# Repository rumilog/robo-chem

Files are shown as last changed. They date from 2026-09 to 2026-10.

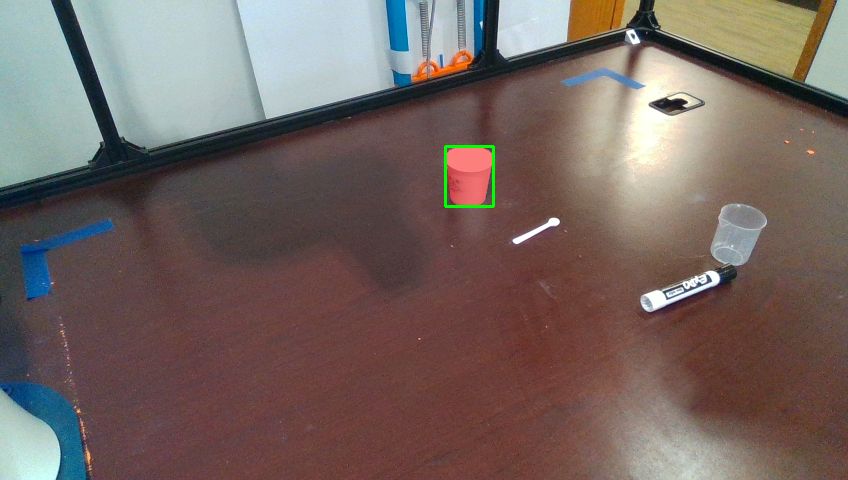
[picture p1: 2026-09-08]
diag_out/mask_white_paper_cup_cam2.png

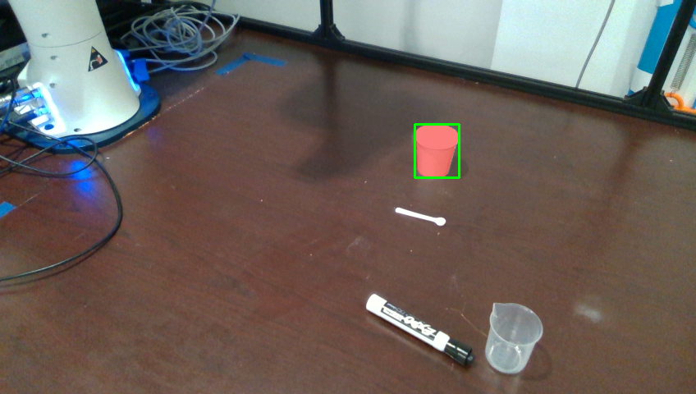
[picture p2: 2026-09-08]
diag_out/mask_white_paper_cup_cam3.png

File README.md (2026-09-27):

# robo-chem

Autonomous robotic chemist stack for a **Franka Panda** arm in a **RealSense** camera cage. Skills use multi-view SAM 3 segmentation, fused 3D localization, and frankapy motion. A VLM orchestrator can plan tasks; individual skills can also be run directly from the CLI.

Barati Farimani Lab, CMU.

---

Working in this repo: read [`progress.md`](progress.md) before you start and
update it when you finish — see [`CLAUDE.md`](CLAUDE.md).

## Requirements

| Piece | Notes |
| --- | --- |
| Franka + `franka-interface` / ROS Noetic | Control PC stack under `/home/rumi/frankapy` |
| Python 3.8 venv with frankapy | `/home/rumi/franka` (activated by `scripts/env.sh`) |
| Perception env (Python 3.10) | `perception_env/` — runs the grounding service |
| SAM 3 weights | `weights/sam3.pt` (see `scripts/fetch_sam3.py`) |
| OpenAI API key (optional) | `.env` / `OPENAI_API_KEY` for VLM planning and labelled-cup matching |

Do **not** stream all four RealSense cameras at once — capture is sequential (open → frame → close) to avoid USB bus freezes.

---

## Quick start

### 1. Robot / ROS env

```bash
cd /home/rumi/Desktop/robo-chem
source scripts/env.sh
```

### 2. Grounding service (separate terminal)

```bash
cd /home/rumi/Desktop/robo-chem
perception_env/bin/python perception_service/grounding_service.py \
  --backend sam3 --model weights/sam3.pt --no-exemplars
```

Service listens on `http://127.0.0.1:5005` by default. The printed scoop is
the text prompt `"white plastic tool"`. Exemplar matching (DINOv2 plus a
second SAM, for the stirrer and the holder) stays unloaded unless you pass
`--exemplars exemplars`. See `exemplars/README.md`.

### 3. Run a skill

```bash
source scripts/env.sh
python scripts/run_experiment.py --skill pick_up \
  --params '{"object_name":"plastic beaker","z_offset":0.02,"squeeze":0.013}'
```

---

## Validated skill commands

### Pick beaker (upright top-down)

```bash
python scripts/run_experiment.py --skill pick_up \
  --params '{"object_name":"plastic beaker","z_offset":0.02,"squeeze":0.013}'
```

Opens the gripper, **`reset_joints`** (joint-space home) before scanning, then top-down grasp. Closing uses measured width − squeeze.

### Pick spoon (lower workspace floor)

```bash
python scripts/run_experiment.py --skill pick_up \
  --workspace-min 0.25 -0.40 -0.13 \
  --params '{"object_name":"larger spoon","z_offset":0.0,"grasp_force":1.0}'
```

### Pour into white paper cup

```bash
python scripts/run_experiment.py --skill pour \
  --params '{"target_container":"white paper cup","pour_angle":90,"hold_duration":2,"forward_offset":-0.08}'
```

- `reset_joints` before scanning and again after the pour hold
- Tips toward the robot base (−X) to 90°
- Each 10° tip step advances the EE **+X by 0.25 cm** (`tip_advance_m`) so the mouth stays over the cup
- Tune `forward_offset` / `tip_advance_m` if the stream misses the cup

### Scoop from a labelled cup

Cups sit on handwritten labels (`CITRIC ACID`, `BAKING SODA`, …). Locate matches label → cup via GPT-4o + multi-instance SAM:

```bash
python scripts/run_experiment.py --skill scoop \
  --workspace-min 0.25 -0.40 -0.13 \
  --params '{"powder_source":"citric acid","tool_length":0.08}'
```

Offline label check (no robot):

```bash
python scripts/check_labeled_cups.py \
  --images-dir "scene_captures/spoon graspped_20260909_155259" \
  --label "citric acid" \
  --out-dir diag_out/labeled_cups
```

---

## Repository layout

```
robo-chem/
├── robochem/                 # Python package
│   ├── skills/               # pick_up, pour, scoop, place, …
│   ├── agents/               # LLM planner: scene → plan → skill call
│   ├── vision/               # multi-cam localizer, grasp analyzer, grounding client
│   ├── orchestrator/         # the closed loop over the agents and the skills
│   └── verification/         # chemistry outcome checks
├── perception_service/       # Flask SAM 3 / GroundingDINO / exemplar service
├── scripts/
│   ├── env.sh                # ROS + frankapy + PYTHONPATH
│   ├── run_experiment.py     # main skill / task entry
│   ├── calibrate_cameras.py  # board-free cube calibration
│   ├── capture_scene.py      # dump color/depth stills
│   ├── register_object.py    # teach an object SAM cannot be told about
│   └── smoke_test_*.py
├── weights/                  # sam3.pt, etc.
├── exemplars/                # objects registered by appearance, not by name
├── calibration_out/          # extrinsics, taught poses
├── diag_out/                 # debug overlays / fused clouds
├── scene_captures/           # saved multi-cam scenes
├── progress.md               # detailed status & known-good params
└── IMPLEMENTATION_PLAN.md    # longer design notes
```

---

## Skills

| Skill | Role |
| --- | --- |
| `pick_up` | Segment → fuse → top (or side) grasp → lift |
| `pour` | Locate target → tip toward base → hold → `reset_joints` |
| `scoop` | Dig from a powder source (optionally by reagent label) |
| `place`, `dispense`, `stir`, `move_to`, `tilt` | Other manipulation |
| `open_gripper` / `close_gripper` | Gripper |
| `analyze_scene`, `locate_object`, `check_container` | Perception |

Many skills besides `pick_up` / `pour` are less hardened (workspace clamps, reach retries, pre-scan home).

Run any skill:

```bash
python scripts/run_experiment.py --skill <name> --params '<json>'
```

---

## Natural-language tasks (the LLM agents)

`--task` runs the agent pipeline in [`robochem/agents/`](robochem/agents/): it
looks at the bench through the cage, plans sub-tasks, chooses a skill and its
parameters for each one, executes them, and replans when one fails. It is
robomail_Aliyah's multi-agent planner — structured output, a robot capability
profile, closed-loop correction — with its fake executor replaced by the real
`SkillsExecutor`.

```bash
source scripts/env.sh
python scripts/run_experiment.py --task "Scoop citric acid into the white paper cup"
```

**See the plan without moving the arm.** `--dry-run` runs every LLM stage and
prints the skill call it would make for each sub-task, then stops. This is the
cheap way to check a task before committing the bench to it:

```bash
perception_env/bin/python scripts/run_experiment.py --sim --no-viewer --dry-run \
    --workspace-min 0.25 -0.40 -0.13 \
    --task "Scoop citric acid into the white paper cup"
```

```
[scene] 4 objects: citric acid cup, larger spoon, plastic beaker, white paper cup
[plan] 4 sub-tasks
   1. Pick up the larger spoon
   2. Scoop citric acid from the citric acid cup with the held larger spoon
   3. Dump the loaded larger spoon into the white paper cup
   4. Place the larger spoon beside the citric acid cup
```

Drop `--dry-run` and the same run executes. Step 2 then comes out as:

```
[step 2] Scoop citric acid from the citric acid cup with the held larger spoon
   -> --skill scoop --params '{"powder_source": "citric acid cup",
                               "tool_offset": [-0.0306, -0.0015, 0.0039]}'
```

That `tool_offset` is not a number the model invented, and it is not in the dry
run either: `pick_up` measured it off the point cloud at the moment it grasped
the spoon, and the orchestrator put it in the prompt for the next step. A dry run
grasps nothing, so there is nothing to measure and the parameter is absent.

| Flag | Effect |
| --- | --- |
| `--dry-run` | Plan in full, execute nothing |
| `--max-retries N` | Corrective replanning attempts (default 3) |
| `--no-verify` / `--verify` | Chemistry check at the end. On by default on hardware, off in `--sim`, which has no chemistry to check |
| `--legacy-planner` | The older single-prompt `VLMOrchestrator` |

Every run writes a JSON record to `--log-dir` (default `experiments/`) holding the
scene, every plan and correction, every skill call with its parameters, and what
each one returned.

### How the pieces fit

| Stage | Module | Does |
| --- | --- | --- |
| Scene | `agents/scene.py` | Names what is on the bench, using names perception can actually resolve |
| Plan | `agents/planner.py` | Goal → ordered sub-tasks; also the corrective replan |
| Skill call | `agents/skill_planner.py` | One sub-task → one `SkillsExecutor` call, with parameters |
| Vocabulary | `agents/skill_catalog.py` | The closed skill list, generated from `SKILL_REGISTRY` |
| Loop | `orchestrator/agent_orchestrator.py` | Executes, tracks the gripper, replans on failure |

Three things are deliberate and worth knowing:

- **The model does not author trajectories.** It picks the skill and its
  arguments; the motion inside each skill is hand-written and grounded by SAM 3.
  This is a weaker autonomy claim than robomail_Aliyah's "all motion comes from
  the LLM Step Planner", and every trial record says so under `provenance`.
- **Object names are grounded, not captions.** A name goes straight to
  `VisionSystem.locate`. Where the cell can enumerate its bench — the simulator
  can — the scene agent must name objects from that inventory, so it cannot plan
  against a "measuring scoop" the bench calls a "larger spoon".
- **Tool offsets come from perception.** `pick_up` measures where a grasped
  tool's working end sits and reports it; the orchestrator hands that
  measurement to the agent planning the next step rather than letting the model
  guess a number it cannot see.

Instead of a typed task, `--instruction-image` reads the goal off a photographed
protocol page.

**Status.** Exercised end to end in `--sim`: plan, execute, an autonomous replan
after a failed `place`, success. With granules on, 2 of 90 citric acid grains
reached the paper cup — the scoop's yield is limited by `measure_tool_offset`
reading the bowl 24 mm shallower than CAD, which is a perception limitation that
predates this pipeline (see `progress.md`). **Not yet run on the arm.** The hardware path
differs in two ways worth watching the first time: object names are open
vocabulary rather than a bench inventory, so a name the scene agent invents can
fail to ground; and verification is on by default.

---

## Calibration & perception

1. Prefer **live RealSense factory intrinsics** (old `.intr` files were corrupt).
2. Extrinsics: green cube in gripper + Kabsch (`scripts/calibrate_cameras.py`).
3. Validate with `scripts/validate_calibration.py` / `scripts/check_object.py`.
4. Prefer prompt **`plastic beaker`** for the red translucent beaker; use **`--backend sam3`**.
5. The printed scoop is the prompt **`white plastic tool`**. Appearance
   matching for the stirrer and holder is opt-in (`--exemplars exemplars`);
   it is off by default because DINOv2 plus a second SAM exhausts RAM
   (`exemplars/README.md`).

---

## Simulation (no robot, no cage)

`robochem/sim/` runs the **same skills** against a MuJoCo Franka Panda so motions
can be watched before they touch hardware. The arm is mujoco_menagerie's vendor
Panda model with the Franka Hand; the four cage cameras are placed at the
extrinsics in `calibration_out/` and given the cage's frame geometry (848x480 at
a 42.5° vertical field, so fx = fy ≈ 617 as the D435 reports), rendered for
depth and segmentation, and back-projected through the project's own
`ObjectLocalizer` / `VisionSystem` fusion — so perception really reconstructs
the props from four views, with real self-occlusion, and rejects them when the
views disagree.

`SimFrankaArm` implements the frankapy surface the skills use and `SimVision`
the `VisionSystem` surface, so `SkillsExecutor` is unmodified. The simulator has
**no frankapy and no ROS**, so it runs out of `perception_env` (Python 3.10),
*not* the robot venv — do **not** `source scripts/env.sh` first.

### Setup (once)

```bash
bash scripts/setup_sim.sh
```

Reuses `perception_env/` if present, otherwise builds `sim_env/`; installs the
dependencies, pre-fetches the Panda MJCF into `~/.cache/robot_descriptions/`,
and runs the smoke test. Full setup notes, including a fresh machine after a
`git pull`, are in [`robochem/sim/README.md`](robochem/sim/README.md).

### Run a skill in the viewer

```bash
perception_env/bin/python scripts/run_experiment.py --sim \
  --skill pick_up --params '{"object_name":"plastic beaker","z_offset":0.02,"squeeze":0.013}'

perception_env/bin/python scripts/run_experiment.py --sim --sim-granules \
  --skill pour --params '{"target_container":"white paper cup","pour_angle":90,"hold_duration":2,"forward_offset":-0.08}'

perception_env/bin/python scripts/run_experiment.py --sim \
  --workspace-min 0.25 -0.40 -0.13 \
  --skill scoop --params '{"powder_source":"citric acid","tool_length":0.08}'
```

| Flag | Effect |
| --- | --- |
| `--sim-speed N` | Genuinely moves the arm N× faster (compresses commanded durations). Fling-and-spill at high N is real, not an artifact — use `1.0` when granule behaviour matters. |
| `--sim-fast` | Keeps commanded durations, just skips the wall-clock wait. This is the flag for "same motion, less waiting". |
| `--no-viewer` | Headless (CI, remote shells) |
| `--sim-granules` | Loose particles in the beaker and reagent cups, so pours and scoops move material |
| `--sim-tool-length M` | Bolt a fixed tool of length M onto the hand and move `franka_tool` out to its tip |
| `--sim-grasp-mode` | `magnet` (kinematic attach on close, default) or `physics` (friction contacts) |
| `--sim-hold S` | Seconds to keep the window open afterwards (default: until you close it) |

### From Python

```python
from robochem.sim import build_cell

cell = build_cell(viewer=True, granules=True)
cell.skills.execute("pick_up", {"object_name": "plastic beaker", "z_offset": 0.02})
cell.arm.hold()      # keep watching
cell.close()
```

Edit the bench (what is on the table, and where) in `robochem/sim/bench.py`.

### What it is and is not

- Cartesian targets are solved by damped least-squares IK over the seven arm
  joints and tracked to **under a millimetre**, with gravity compensated as the
  real controller does. An unreachable target leaves the arm short, so the
  skills' own arrival checks fire rather than being papered over.
- Reconstructed centroids land within a few millimetres of truth for the cups;
  the spoon reads ~25 mm off its body origin because its point cloud includes
  the bowl.
- It does **not** model fluid, powder rheology, RealSense noise characteristics,
  frankapy impedance, or force thresholds. Granules are bouncy spheres — they
  show *where a stream goes*, not how a powder behaves.

---

## Smoke tests

```bash
# Gripper / small moves only (no vision)
python scripts/smoke_test_motion.py
python scripts/smoke_test_motion.py --move

# Pick (+ optional pour) with pauses
python scripts/smoke_test_skills.py
python scripts/smoke_test_skills.py --pour
```

No hardware needed (run these from `perception_env`, without `scripts/env.sh`):

```bash
# Skill geometry and failure logic against a fake arm
perception_env/bin/python scripts/test_skills_offline.py

# The agent loop against a fake model: vocabulary, parameter checking,
# gripper bookkeeping, replanning. Needs no API key.
perception_env/bin/python scripts/test_agents_offline.py

# Perception + motion + pick/pour/scoop against the simulated cell
perception_env/bin/python scripts/smoke_test_sim.py
perception_env/bin/python scripts/smoke_test_sim.py --viewer --speed 2
```

---

## Related docs

| Doc | Contents |
| --- | --- |
| [`progress.md`](progress.md) | Current validated commands, design choices, known issues |
| [`IMPLEMENTATION_PLAN.md`](IMPLEMENTATION_PLAN.md) | Broader architecture plan |
| [`SKILLS_ROADMAP.md`](SKILLS_ROADMAP.md) | Skill hardening roadmap |
| [`robochem/sim/README.md`](robochem/sim/README.md) | MuJoCo preview of the cell: setup, usage, troubleshooting |
| [`robomail/docs/progress.md`](robomail/docs/progress.md) | Older PLATO / agent-pipeline notes |

---

## License / attribution

Research software for the Autonomous Robotic Chemist project (Barati Farimani Lab). Robot control depends on frankapy / Franka; perception on Meta SAM 3 and RealSense; simulation on MuJoCo and the Franka Panda model from DeepMind's mujoco_menagerie (Apache-2.0).

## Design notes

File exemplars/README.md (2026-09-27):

# Registered objects (exemplar vocabulary)

One `.npz` per custom object: DINOv2 embeddings of reference crops you boxed by
hand. These are the vocabulary for things SAM 3 has no word for — the printed
stirrer, the cranked scoop — and they are cell calibration, same as
`calibration_out/`: small, and meant to be committed.

## Why these exist

SAM 3 is open-vocabulary, not unlimited. `scripts/sweep_prompts.py` spent twenty
phrases on the printed scoop and the best honest hit was `"scoop"` on 2/4
cameras; the stirrer sweep in `diag_out/stirrer_prompts/` is the same story. The
phrases that score *well* (`"white object"`, 0.95 on 4/4) are matching the cups.
No wording fixes this — the concept is not in the model.

So these objects are matched by appearance instead. The grounding service
segments everything in the frame with SAM's automatic mask generator (no prompt,
class-agnostic), embeds each candidate, and returns whichever one looks most like
a reference here. See `perception_service/exemplar_matcher.py`.

## Adding an object

```bash
# 1. put it on the bench, photograph it from every camera
source scripts/env.sh
python scripts/capture_scene.py --label stirrer

# 2. drag a box around it once per camera
perception_env/bin/python scripts/register_object.py --name stirrer \
    --images-dir scene_captures/stirrer_<ts>

# 3. start the grounding service WITH the library (off by default; DINOv2
#    plus a second SAM is too much RAM on this host):
#    perception_env/bin/python perception_service/grounding_service.py \
#        --backend sam3 --model weights/sam3.pt --exemplars exemplars
# 4. check it, and LOOK at the overlays
python scripts/sweep_prompts.py --images-dir scene_captures/stirrer_<ts> \
    --only stirrer --save-overlays diag_out/stirrer_exemplar
```

Register from several captures (`--images-dir` is repeatable) when the tool will
be seen in genuinely different poses — lying on the bench and standing in its
holder are not the same view.

## Two things that silently cost you a match

**Aliases.** `GroundingClient._resolve` rewrites names through
`SAM_PROMPT_ALIASES` *before* the service sees them, and dispatch here is by
name. A skill asking for `"rectangular scoop"` sends `"white plastic tool"`, so
the scoop must be registered with that phrase as an alias or it is never
consulted:

```bash
perception_env/bin/python scripts/register_object.py --name scoop \
    --images-dir scene_captures/new_scoop_<ts> --alias "white plastic tool"
```

`register_object.py` warns when it spots this.

**The model id.** Every file records the encoder that made it. Embeddings from a
different encoder are not comparable to anything the service computes, so a
mismatched file is skipped with a warning rather than scored — re-register if
`EMBED_MODEL_ID` in `exemplar_matcher.py` ever changes.

## Register what you want to GRASP

`ObjectLocalizer.get_object_pose` puts the grasp at the **mean of the fused mask
points**, so the mask defines where the gripper goes. Register the part you mean,
not the assembly it is sitting in.

The stirrer is the white cube; the black cylinder under it is its holder. A first
pass registered "stirrer" as cube + cylinder together, which scored beautifully
(0.95+) and would have driven the gripper into the middle of the *holder*. They
are now two objects — `stirrer` and `stirrer holder` — which also gives
place-back something to aim at, and keeps `stirrer` recognisable once it has been
lifted out and the assembly no longer exists.

A high score means "this is the shape you showed me". It says nothing about
whether that shape was the right thing to show.

## Register every state the object will be seen in

A holder with the tool in it and a holder standing empty are different pictures.
`stirrer_holder.npz` carries both — four views with the stirrer seated (its top
occluded) and four of the empty bore — because the holder gets looked for in
both states: occupied before a pick, empty when deciding where to put the
stirrer back. They are only 0.49-0.83 similar to each other, so one does not
stand in for the other.

The same applies to a tool that will be seen lying on the bench *and* standing
in its holder. `--append` adds views to an existing object; it never replaces
them.

## Multi-part objects

Box the WHOLE tool when you register, even if it is two colours. A two-tone
object is several objects to the mask generator — the stirrer's black body, the
white cube's top and the cube's shaded front face come back as three separate
masks — so no single candidate is ever the whole thing. The matcher glues
neighbouring pieces back together for as long as that improves the match against
your reference, which took the stirrer from 0.64 (body only, head cut off) to
0.95 on cam2. You do not have to do anything for this; it just means the
reference should be the shape you actually want back.

## When something is not found

The point grid is what finds candidates at all, and at the default 32x32 over an
848x480 frame the points land ~26px apart — wider than the scoop's shank. That
produced half a scoop on one camera, and half a scoop legitimately resembles the
stirrer cube more than it resembles a scoop, so the match was refused. The
service retries a missed frame at 48x48 (`--exemplar-retry-points`), which costs
~9s instead of ~4s but only on frames that actually missed.

A per-camera miss is not a failure of the run: localization fuses whatever
cameras did find the object, and three good views beat four with a bad one.

## Reading the numbers

`register_object.py` prints how well the object stands apart: how much its own
views agree, and its best similarity to every other registered object. Own views
at 0.9 and the nearest neighbour at 0.5 is a clean object. Own views at 0.5 and a
neighbour at 0.8 means the crops are mostly table, and no threshold will save it —
register tighter boxes, or make the objects visually different (colour is the
cheap fix). The suggested `--exemplar-thresh` sits between the two.

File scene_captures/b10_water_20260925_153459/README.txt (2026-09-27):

Workstation scene stills for offline perception benchmarking.
Captured: 20260925_153459
Label: b10_water
Cameras: RealSense static cage cams (848x480 BGR + Z16 depth).
Files:
  cam{N}_color.png     - BGR color frame
  cam{N}_depth.png     - raw 16-bit depth (mm)
  cam{N}_depth_viz.png - colorized depth for quick viewing

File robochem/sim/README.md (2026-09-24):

# Simulated Franka cell (`robochem.sim`)

A MuJoCo model of this lab's cell — Franka Emika Panda, Franka Hand, four-camera
RealSense cage — that the **real skills run against unmodified**, so arm motions
can be watched and debugged with no hardware present.

> **Setting this up on a new machine?** Run `bash scripts/setup_sim.sh` from the
> repo root and skip to [Verify](#3-verify). The rest of this file explains what
> that does and how to use the result.

---

## What it actually simulates

`SkillsExecutor` talks to the arm through thirteen methods and to perception
through the `VisionSystem` surface. `SimFrankaArm` and `SimVision` implement
those two surfaces, so **no skill code is aware of the simulator**:

- **Arm** — mujoco_menagerie's vendor Panda MJCF (real link geometry, joint
  limits, Franka Hand). Cartesian targets are solved by damped least-squares IK
  over the seven arm joints and tracked to under a millimetre, with gravity
  compensated the way the real controller does. An unreachable target leaves the
  arm short, so the skills' own arrival checks fire instead of being papered over.
- **Perception** — each of the four cage cameras is placed at the measured
  extrinsics from `calibration_out/` and rendered for depth and segmentation in
  the real frame geometry: 848x480 at a 42.5° vertical field, which is the D435
  colour stream the cage runs and the intrinsics its depth is deprojected with
  (fx = fy ≈ 617, cx = 424, cy = 240). A prop at the edge of a real view is at
  the edge of the simulated one.
  The segmentation supplies the mask SAM 3 would have produced; everything after
  that is this project's own code — `ObjectLocalizer._depth_to_points`,
  `_transform_points`, `VisionSystem._filter_by_consensus`, `_check_plausible`.
  So a skill sees a genuine multi-view point cloud with real self-occlusion, and
  perception fails the same way when a container is hidden from too many cameras.
- **Grasping** — closing the jaws on a prop attaches it kinematically and reports
  the prop's width back through `get_gripper_width()`, which is what a real grasp
  stalling on an object looks like. `grasp_mode="physics"` uses friction instead.

### What it does not simulate

Fluids, powder rheology, RealSense noise characteristics, frankapy impedance
behaviour, or force thresholds. Granules are bouncy spheres: they show *where a
stream goes*, not how a powder behaves. Depth is also complete where the real
sensor drops out — the simulated beaker returns depth through its transparent
wall, so a passing sim run does not prove the real cage can see a clear
container.

---

## Setup

### 0. Prerequisites

| Need | Detail |
| --- | --- |
| Python | 3.9+. Verified on **3.10** and **3.13** |
| Disk | ~500 MB — mujoco_menagerie is cloned to `~/.cache/robot_descriptions/` on first use |
| Graphics | Any OpenGL. A display for the viewer window; `MUJOCO_GL=egl` for headless |
| **Not** needed | frankapy, ROS, RealSense, SAM weights, `OPENAI_API_KEY` |

The camera extrinsics (`calibration_out/realsense_camera{2,3,4,5}w.npy`) **are
committed**, so a fresh clone gets the real cage geometry. If they are ever
missing the scene falls back to a synthetic camera ring and says so:

```
[sim] No calibration in calibration_out; using a synthetic camera ring
```

`calibration_out/` holds the **measured** extrinsics from the last
`scripts/calibrate_cameras.py` sweep. The robot reads a *different* copy —
`robomail/robomail/vision/calib/`, which `calibrate_cameras.py --apply` installs
into. Until that install runs the two disagree (in this checkout by about 4 cm;
see `shift_from_current_mm` in `calibration_out/report.json`), and a simulated
camera is not where the robot believes its camera is. To preview against what
the robot is actually running, point the sim at the same files:

```bash
sim_env/bin/python scripts/run_experiment.py --sim \
  --sim-calib-dir robomail/robomail/vision/calib ...
```

### 1. Environment

Python environments are **not** in git (`perception_env/`, `sim_env/` are
ignored), so a fresh clone has none. Build one:

```bash
cd /path/to/robo-chem
bash scripts/setup_sim.sh
```

That reuses `perception_env/` if it exists, otherwise creates `sim_env/`, then
installs, pre-fetches the model and runs the smoke test. Pass a path to target a
specific env (`bash scripts/setup_sim.sh path/to/venv`), or set `SKIP_TEST=1` to
install without verifying.

> **Do not `source scripts/env.sh` first.** That activates the Python 3.8
> frankapy venv and sources ROS. The simulator needs neither and will not run
> there.

#### On Windows

`setup_sim.sh` assumes a POSIX venv layout (`bin/python`), so do it directly —
the interpreter lives in `Scripts\` and the rest is identical:

```powershell
winget install --id Python.Python.3.12 -e --scope user
& "$env:LOCALAPPDATA\Programs\Python\Python312\python.exe" -m venv sim_env
sim_env\Scripts\python.exe -m pip install numpy mujoco robot_descriptions opencv-python scikit-learn openai Pillow
sim_env\Scripts\python.exe scripts\smoke_test_sim.py
```

The viewer and offscreen rendering both work through WGL; there is no `MUJOCO_GL`
to set, and `egl` is not available. If `import mujoco` dies with `WinError 1114`,
see Troubleshooting — the Visual C++ runtime needs updating.

<details>
<summary>Manual equivalent, if you would rather not use the script</summary>

```bash
python3 -m venv sim_env
sim_env/bin/pip install numpy mujoco robot_descriptions opencv-python scikit-learn openai Pillow
```

`numpy`, `mujoco` and `robot_descriptions` drive the simulation. `opencv-python`,
`scikit-learn` and `openai` are imported on the way into `robochem.vision`, which
`SimVision` subclasses so reconstruction runs through the real fusion code.
`Pillow` comes in through `ExperimentLogger`, which `run_experiment.py` imports
at module level whether or not the run is simulated. `open3d` is **not**
required — nothing on the simulated path uses it.

Check it with `sim_env/bin/python scripts/run_experiment.py --help`, which
exercises every module-level import and should exit 0.
</details>

### 2. First run downloads the model

The first call clones mujoco_menagerie (a few hundred MB) with a progress bar.
`setup_sim.sh` does this up front so a later run does not appear to hang.

### 3. Verify

```bash
sim_env/bin/python scripts/smoke_test_sim.py
```

Expected tail — **all five groups must pass**:

```
====================================================
  PASS  perception
  PASS  motion
  PASS  pick + pour
  PASS  pick + scoop
  PASS  failure handling
====================================================
all groups passed
```

Add `--viewer` to watch it (`--viewer --speed 2`). Takes a few minutes headless.

`--only` runs just the groups whose name contains what you pass, which is how you
watch one sequence end to end — the skills run against **one** cell, so the spoon
is still in the jaws when `scoop` starts:

```bash
sim_env/bin/python scripts/smoke_test_sim.py --viewer --granules \
  --only scoop --speed 2 --hold 0
```

`--hold 0` leaves the window open until you close it instead of the default five
seconds. Running `pick_up` and then `scoop` as two `run_experiment.py --sim`
commands does **not** work: each process builds its own cell, so the second one
starts with an empty gripper and `scoop` refuses.

---

## Running skills

Same entry point and the same `--params` as the hardware route, plus `--sim`:

```bash
sim_env/bin/python scripts/run_experiment.py --sim \
  --skill pick_up --params '{"object_name":"plastic beaker","z_offset":0.02,"squeeze":0.013}'

sim_env/bin/python scripts/run_experiment.py --sim --sim-granules \
  --skill pour --params '{"target_container":"white paper cup","pour_angle":90,"hold_duration":2,"forward_offset":-0.08}'

sim_env/bin/python scripts/run_experiment.py --sim \
  --workspace-min 0.25 -0.40 -0.13 \
  --skill scoop --params '{"powder_source":"citric acid","tool_length":0.08}'
```

`--skill` can be repeated to run a sequence against one cell; `--params` is
matched to it in order, and a skill given no `--params` runs on its defaults.
This is the only way skills that hand a held tool between them (`pick_up` then
`pour` / `scoop` / `stir`) can work, because a second invocation starts a fresh
cell with an empty gripper. The run stops at the first step that fails and exits
non-zero, naming the step.

| Flag | Effect |
| --- | --- |
| `--sim-speed N` | Genuinely moves the arm N× faster by compressing commanded durations. Spilling at high N is real, not an artifact — use `1.0` when granule behaviour matters |
| `--sim-fast` | Keeps commanded durations, only skips the wall-clock wait. **This** is the flag for "same motion, less waiting" |
| `--no-viewer` | Headless, for CI and remote shells |
| `--sim-granules` | Loose particles in the beaker and reagent cups so pours and scoops move material |
| `--sim-tool-length M` | Bolt a fixed tool of length M (metres) to the hand and move `franka_tool` out to its tip |
| `--sim-grasp-mode` | `magnet` (kinematic attach, default) or `physics` (friction contacts) |
| `--sim-calib-dir DIR` | Where to read `realsense_cameraNw.npy` from. Defaults to `calibration_out/`; point it at `robomail/robomail/vision/calib` to place the cage exactly where the robot currently believes it is |
| `--sim-hold S` | Seconds to keep the window open afterwards (default: until you close it) |

### From Python

```python
from robochem.sim import build_cell

cell = build_cell(viewer=True, granules=True)
cell.skills.execute("pick_up", {"object_name": "plastic beaker", "z_offset": 0.02})
cell.arm.hold()     # keep watching until the window is closed
cell.close()        # always: see the segfault note in Troubleshooting
```

`cell.arm` is the frankapy stand-in, `cell.vision` the `VisionSystem` stand-in,
`cell.skills` an ordinary `SkillsExecutor`. `cell.vision.ground_truth(name)`
gives a prop's true position, for checking what perception did.

### Headless (no display)

```bash
MUJOCO_GL=egl sim_env/bin/python scripts/smoke_test_sim.py
```

`egl` is verified working with `DISPLAY` unset. Offscreen rendering for the
cameras works regardless; only the interactive window needs a display, and it
degrades gracefully:

```
[sim] Viewer unavailable (...); running headless
```

---

## Layout

| File | Role |
| --- | --- |
| [`scene.py`](scene.py) | Compiles the MJCF: Panda + Hand, the `franka_tool` TCP site, the four cage cameras, the table, the props. Also builds the arm-only model used for IK |
| [`sim_arm.py`](sim_arm.py) | `SimFrankaArm` — the frankapy surface, DLS IK, Cartesian interpolation, kinematic grasping |
| [`sim_vision.py`](sim_vision.py) | `SimVision` — renders depth + segmentation, deprojects through the project's real fusion path |
| [`bench.py`](bench.py) | **What is on the table, and where.** Edit here to change the scene |
| [`rigid_transform.py`](rigid_transform.py) | `RigidTransform` shim, so the skills build poses without autolab_core (which exists only in the robot venv) |
| [`../../scripts/smoke_test_sim.py`](../../scripts/smoke_test_sim.py) | End-to-end check: perception, motion, pick+pour, pick+scoop, failure handling |
| [`../../scripts/capture_sim_scene.py`](../../scripts/capture_sim_scene.py) | Colour + depth stills from the simulated cage, in the same filenames `capture_scene.py` writes on hardware |
| [`../../scripts/setup_sim.sh`](../../scripts/setup_sim.sh) | One-command setup on a new machine |

### Changing the bench

Props are described semantically in `bench.py` and compiled to MJCF. Their names
are the queries the skills already use (`"plastic beaker"`, `"white paper cup"`,
`"larger spoon"`), and a `label` makes a cup resolve from a reagent name the way
the real labelled-cup path does:

```python
Prop(name="plastic beaker", pos=(0.46, 0.14), radius=0.035, height=0.095,
     rgba=(0.75, 0.85, 0.95, 0.55), fill=30)          # fill = granules inside
```

The table top is `z = 0`, which is also the Panda's base plane, matching the real
cell where object centroids land just above zero.

### The stirrer and its holder

`stirrer v1.stl` and `stirrer holder.stl` are both on the bench at (0.62, 0.14),
on the same axis. The two are authored in **one assembly frame**, so they take
the same orientation and their heights line up directly: the stirrer starts
seated in the holder, its head resting on the holder's top face and its rod
hanging in the bore. That is the point of the holder — the tool is always
presented upright, so the gripper can take it from straight above like anything
else.

| Part | Geometry |
| --- | --- |
| Stirrer | 30 mm grasp head on a 10 mm ⌀ rod, 66 mm of rod, 96 mm overall. Head centre to rod tip is **81 mm** — that is `tool_length`. |
| Holder | 50 mm ⌀ block, 85 mm tall, bored 12 mm with a chamfer over the top 19 mm. Welded to the bench: it is a fixture. |

The holder is a fixture, so it is deliberately **not graspable** — the stirrer's
head sits directly above it, and without that rule a closing gripper takes the
holder instead.

The full cycle, in one session:

```bash
sim_env/bin/python scripts/run_experiment.py --sim \
  --skill pick_up --params '{"object_name":"stirring rod"}' \
  --skill stir    --params '{"target_container":"plastic beaker","tool_axis":"z","tool_length":0.081,"revolutions":3}' \
  --skill place   --params '{"target_location":"stirrer holder","on_top":true,"release_clearance":0.015,"stop_force_n":1.0}'
```

| Parameter | Why |
| --- | --- |
| `tool_axis: "z"` | The default `"x"` is for a spoon gripped across its flat handle, which has to be stood up with a quarter turn. This rod is gripped end-on and is *already* vertical; the `"x"` check reads that correct pose as 90° off and would tip it flat. |
| `tool_length: 0.081` | Head centre (the TCP) to rod tip. `stir` puts the wrist at `rim_z - stir_depth + tool_length`, so without this the tip never reaches the liquid. |
| `on_top: true` | `place` defaults to setting things down *beside* the target. Without this the stirrer is laid on the bench next to the holder, where it falls over. |
| `release_clearance: 0.015` | Half the head. Only a starting guess when `stop_force_n` is set — the probe begins above it and feels its way down. |
| `stop_force_n: 1.0` | Stop the descent and release the instant the tool pushes back this hard. Contact means the head has landed on the holder's rim, so it is seated. |

The return is a blind insertion: the bore is 2.5 mm wider than the rod, and what
makes it work is the chamfer, which catches a rod arriving up to ~14 mm off axis
and walks it down.

### Seating by force

`place` cannot know where to let go from geometry alone. How far the stirrer
hangs below the TCP changes with every grasp — measured at 6–8 mm of variation
run to run — and the scanned holder height carries a few millimetres of its own
error. `stop_force_n` sidesteps both: descend in `probe_step` increments and
release the moment the tool pushes back harder than the threshold.

Measured curve, pressing the stirrer onto its holder:

| Head underside | Upward force |
| --- | --- |
| 0.0857 m (just clear) | 0.00 N |
| **0.0850 m (on the rim)** | **1.84 N** |
| 0.0843 m | 4.33 N |
| 0.0832 m | 7.11 N |
| 0.0809 m | 11.70 N |

So 1 N triggers within a millimetre of flush, which is the intent. Two details
this depends on:

- `SimFrankaArm.get_ee_force_torque()` matches frankapy's: six floats, base
  frame, signed as the force the world exerts *on* the robot. A magnet grasp
  carries the prop kinematically, so nothing it touches reaches the finger
  joints and a wrist sensor would read zero — the sim sums contacts on
  everything moving with the wrist instead, held prop included.
- The seating faces carry a stiffer `solref`/`solimp` than the MuJoCo default,
  which otherwise squashes for millimetres before pushing back and smears the
  contact event into a ramp no threshold can find.

If the probe never reaches the threshold it keeps hold and fails, rather than
opening the gripper at whatever height the scan produced.

The whole cycle is run by the `pick + stir` group of `smoke_test_sim.py`, and the
refuse-to-drop behaviour by the `force guard` group.

## Troubleshooting

| Symptom | Cause and fix |
| --- | --- |
| `ModuleNotFoundError: No module named 'cv2'` (or `sklearn`, `openai`) | Incomplete install — `robochem.vision` needs them on import. Re-run `scripts/setup_sim.sh` |
| `ModuleNotFoundError: No module named 'mujoco'` | Running the wrong interpreter. The sim is not in the frankapy venv; use the env `setup_sim.sh` built |
| `OSError: [WinError 1114] A dynamic link library (DLL) initialization routine failed` on `import mujoco` (Windows) | The machine's Visual C++ 2015-2022 runtime predates the mujoco wheel, and every mujoco version fails the same way. Confirm it in Event Viewer — Application: a `python.exe` crash naming `MSVCP140.dll` with `0xc0000005`. Fix with `winget upgrade --id Microsoft.VCRedist.2015+.x64` (needs admin; 14.44 or newer works). A venv-local copy of the runtime does **not** help: System32 wins once the DLL is loaded |
| `ImportError: ... frankapy` | You sourced `scripts/env.sh`, or are running the hardware path. `--sim` imports frankapy lazily and never on the simulated route |
| `openai.OpenAIError: Missing credentials` | Only from constructing `VisionSystem` directly. `SimVision` handles this; no key is needed for simulation |
| Process exits `139` / **segmentation fault after the run finishes** | The MuJoCo viewer handle must be garbage-collected before interpreter shutdown. `cell.close()` (and `--sim`) already does this — call it, and do not hold your own reference to `cell.arm._viewer` |
| First run seems to hang | It is cloning mujoco_menagerie. Let it finish, or pre-fetch with `setup_sim.sh` |
| `[sim] jaws closed on nothing` | The gripper closed with no prop between the jaws. Usually a grasp pose that missed, which is the simulator reporting a real failure |
| `[SimVision] Cameras could not agree on 'x'` | Views disagree beyond `consensus_tolerance` — normally the arm occluding the prop. Same rejection the real stack makes |
| Granules fling everywhere | `--sim-speed` above ~2 genuinely accelerates the motion. Use `--sim-fast` instead when you want speed without changed dynamics |

---

## Known accuracy

Measured by `scripts/smoke_test_sim.py` on the default bench:

- Cartesian targets reached to **< 0.5 mm** (hardware `reach_tol` is 35 mm).
- Cup centroids reconstruct within **~1–13 mm** of truth from four cameras.
- The spoon reads **~28 mm** off its body origin — its point cloud includes the
  bowl while the origin is mid-handle. Expected, not an error. It reconstructs to
  **78 x 29 x 26 mm** against the STL's 69.5 x 20.5 x 31.5 mm, the spread being
  depth noise plus PCA axes that do not line up with the CAD axes.
- Pouring at `--sim-speed 1` with `--sim-granules` lands 27/30 particles in the
  target cup, with the median **~3 cm past cup centre in +X** — the `tip_advance_m`
  of 0.25 cm per 10° accumulating. Worth checking against hardware.

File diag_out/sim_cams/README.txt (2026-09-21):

Simulated cage stills, rendered by robochem.sim.
Captured: 2026-09-21T01:01:44
Label: sim
Extrinsics: calibration_out
Cameras: MuJoCo cameras at the cage's measured extrinsics, 848x480, fovy 42.5 (fx = fy = 617, cx = 424, cy = 240).
Files:
  cam{N}_color.png     - BGR colour frame
  cam{N}_depth.png     - 16-bit depth (mm), no sensor dropout
  cam{N}_depth_viz.png - colorized depth for quick viewing
  grid.png             - all cameras on one sheet

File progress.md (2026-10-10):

# Progress — robo-chem (Franka + RealSense)

Last updated: 2026-10-08

Live manipulation stack for the Franka Panda + RealSense cage. Related but
separate from the PLATO/agent notes in [`robomail/docs/progress.md`](robomail/docs/progress.md).

---

## Working commands (validated 2026-09-08 / 2026-09-09)

Prereqs: franka-interface/ROS up, grounding service on SAM 3, then:

```bash
cd /home/rumi/Desktop/robo-chem
source scripts/env.sh
```

Grounding — **one terminal is enough**, background it:

```bash
scripts/grounding.sh start      # idempotent; restart | status | stop | log
```

It has to be its own *process* (perception_env is Python 3.10 for SAM 3; the
skills run in the frankapy Python 3.8 venv) but not its own *terminal*.

Still available by hand if preferred:

```bash
perception_env/bin/python perception_service/grounding_service.py \
  --backend sam3 --model weights/sam3.pt --no-exemplars
```

**DINOv2 is not loaded.** `scripts/grounding.sh` passes `--no-exemplars`.
The printed scoop is the SAM 3 phrase `"white plastic tool"` again
(`scoop`, `rectangular scoop`, `printed scoop`, and `measuring scoop` all
rewrite to it). Exemplar matching still exists and still works — measured
0.95-1.00 on 2026-09-25 — but it loads DINOv2 plus a second SAM on top of
SAM 3, and that combination exhausted this 15GB host. Turn it back on only
with an explicit `--exemplars exemplars` on the python command, not via
`grounding.sh`.

### Pick beaker (upright top-down grasp)

```bash
python scripts/run_experiment.py --skill pick_up \
  --params '{"object_name":"plastic beaker","z_offset":0.02,"squeeze":0.013}'
```

- Opens gripper, **`reset_joints`** (joint-space home) before multi-cam scan
- Upright **top** grasp (no 25° pour tip / spout align)
- Width close = measured diameter − squeeze (`grasp=False`)
  — soft cups still need `"force_limited": false`; default is now close-on-contact

### Pick larger spoon (flat object — lower workspace floor)

```bash
python scripts/run_experiment.py --skill pick_up \
  --workspace-min 0.25 -0.40 -0.13 \
  --params '{"object_name":"larger spoon","z_offset":0.0,"grasp_force":1.0}'
```

- Spoon sits ~z −0.01; default workspace floor (0.015 m) clamps the grasp too high
- `--workspace-min … -0.13` lowers the Z floor so fingers can reach the table
- Force-limited close at 1 N (`force_limited` default True); omit large positive `z_offset`

### Scoop from a labelled cup (reagent name → cup instance)

White paper cups sit on handwritten paper squares (`BAKING SODA`, `CITRIC ACID`,
`RED CABBAGE POWDER`, `Water`). SAM alone cannot tell them apart; locate now:

1. Segments **all** `white paper cup` instances (`return_all` on the grounding service)
2. Asks GPT-4o which label is under each numbered cup
3. Fuses the matching cup in 3D for scoop / pour / place

**Restart the grounding service** after pulling this change (needs `return_all`).

Offline check on stills (no robot):

```bash
python scripts/check_labeled_cups.py \
  --images-dir "scene_captures/spoon graspped_20260909_155259" \
  --label "citric acid" \
  --out-dir diag_out/labeled_cups
```

Scoop (hold the spoon first), using the reagent label as `powder_source`:

```bash
python scripts/run_experiment.py --skill scoop \
  --workspace-min 0.25 -0.40 -0.13 \
  --params '{"powder_source":"citric acid","tool_length":0.08}'
```

- Measure / tune `tool_length` for the held spoon before trusting dig depth
- Direct SAM category names (`plastic beaker`, `larger spoon`, `white paper cup`)
  still skip the label path
- **Camera 2's crop was the cup, not the paper** (2026-09-25,
  `scene_captures/b10_water_20260925_153459`). SAM boxed the clear cup at
  (390, 233)–(457, 302). The 0.9× pad ended at y=331. `B 10 ML WATER` is on
  the sheet in front of the cup, down to about y=450, so the reader saw a
  sliver of `10 ML` and returned null (`labels [none]`). A second mask of
  the same cup (score 0.32) was then greyed over that sliver. The crop now
  follows the white sheet downward and sideways, and does not pad upward
  into the reagent behind the cup — that upward pad made the reader say
  `A 10 ML WATER` and `B 5 ML NaCl` for a crop that also contained the B
  sheet. Re-read of those stills: cam 2 matches `B 10 ML WATER` at score
  0.79, cam 3 at 0.91, cam 5 at 0.89. Cam 4 still reads the B cup as
  `A 10 ML WATER` and is not used.
- **One camera that reads the label is enough** (2026-09-25 dump of
  `B 10 ml water`). Cam 3 read `B 10 ML WATER` at score 0.90, anchor
  `[0.4081, 0.0357, 0.0055]`. Cam 4 was a projection match (score 0.73) whose
  centroid was 52 mm away, so the 50 mm pairwise rule rejected both and the
  direct SAM prompt `"B 10 ml water"` found nothing. If exactly one camera
  read the text, that camera's cloud is used alone. Two cameras that both
  read the label and still disagree are still refused. The 50 mm tolerance
  was not loosened.

### Pour into white paper cup

```bash
python scripts/run_experiment.py --skill pour \
  --params '{"target_container":"white paper cup","pour_angle":90,"hold_duration":2,"forward_offset":-0.08}'
```

- **`reset_joints`** before scanning the cup
- Always tips **toward robot base (−X)** to 90° (no away-from-base fallback)
- Each 10° tip step advances EE **+X by 0.25 cm** (`tip_advance_m`) so the
  mouth does not drift toward the base as it tips
- `forward_offset=-0.08` sets the initial pour site (validated)
- After hold: **`reset_joints`** (joint-space home)
- Stuck tip steps are **retried** (longer duration) before failing

---

## What works

| Area | Status |
| --- | --- |
| Env bring-up (`scripts/env.sh`, frankapy Py3.8 + ROS Noetic) | Working |
| SAM 3 grounding service (`perception_service/`, `weights/sam3.pt`) | Working; prefer over GroundingDINO. DINOv2 is off |
| Scoop via the text prompt `"white plastic tool"` | The live path again (see below). Partial on the 2026-09-18 sweep: cam5 the whole tool, cam2 the handle only |
| Exemplar matching (`exemplars/`, DINOv2 + SAM-vit-base) | Measured 0.95-1.00, **not loaded**. Opt-in with `--exemplars exemplars` |
| Sequential RealSense capture (cams 2–5, one at a time) | Working — avoid streaming all four at once (USB wedge) |
| Live factory intrinsics + board-free cube extrinsic calib | Working (~3–6 mm held-out) |
| `pick_up` upright top grasp + reset_joints pre-scan | Working (beaker + spoon params above) |
| `pour` tip toward/away base + stall detection + site offsets | Working with `forward_offset=-0.08` |
| Smoke scripts | `scripts/smoke_test_skills.py`, `scripts/smoke_test_motion.py` |

---

## Calibration / perception notes

- Corrupt `.intr` files (fy≈fx/2) were a major early failure mode; pipeline now
  prefers **live RealSense factory intrinsics**
- Extrinsics: HSV green cube fiducial + Kabsch; install under robomail
  `calib/` with dated backup
- Scripts: `calibrate_cameras.py`, `validate_calibration.py`, `check_object.py`
- Prompt `"plastic beaker"` detects the red translucent beaker more reliably
  than bare `"beaker"`

---

## Custom objects: exemplar matching (added 2026-09-25, unloaded the same day)

Turned back off on 2026-09-25 because the live service was SAM 3 **plus**
DINOv2-base **plus** SAM-vit-base. The process that had all three loaded was
idle at **7.1GB resident, 9.2GB peak, 1.4GB swap**. After
`scripts/grounding.sh restart` with `--no-exemplars`, `/health` reports
`exemplars: []` and the idle process is **360MB, 0 swap**. The 3.3GB
weights are not on the GPU until the first `/segment`. Measured on the
14:40 pick of `"white plastic tool"`: camera 2 took **94.6s**, camera 3
took **0.35s**, and the robot terminal printed nothing during that wait,
which reads as a hang. After that query the service sits at 3.2GB resident
and 5.2GB of GPU, 0 swap. A four-camera `segment_instances` was already
5.85GB resident / 8.90GB peak before the extra models. The scoop is
`"white plastic tool"` again.

**The stirrer is `"white cube"` (found 2026-09-25, real robot).** All the
prompts in `diag_out/stirrer_prompts/` described the whole black assembly or
guessed at tool words (`"stirrer"`, `"stirring rod"`, `"black cap"`) and none
of them separated the grasp point from the holder cleanly enough to trust.
Describing only the part the gripper actually needs — the **white** cube
sitting on the black cylinder, not the assembly, not the cylinder — worked:
`pick_up --params '{"object_name":"white cube",...}'` grasped it and the chain
carried into `stir` (which requires `is_gripper_holding()`, so reaching that
step is itself the confirmation). Added `"cube"` and `"cylinder"` to
`label_resolver._DIRECT_SAM_KEYWORDS` so `"white cube"` skips the reagent-label
path and goes straight to a SAM 3 text prompt — without that it would first
scan every `"white bowl"` for a paper reading "white cube" and only fall back
after failing there.

The holder itself is still unconfirmed by this route — try `"black cylinder"`
next, now that it is also a direct keyword.

**`"white cube"` then failed on the robot (2026-09-25).** The error was
`Rejecting 'white cube': extent [0.294 0.39 0.13] exceeds 0.35m`. All four
cameras agreed on the centroid (max pair 34-41 mm), so SAM had found the
right object. Mask areas in `grounding_service.log` are 1,000-2,900 px, the
same as the earlier pick that worked. The mask was fine; the depth behind
it was not.

`_depth_to_points` back-projected every mask pixel's raw depth. Edge pixels
of a small object often carry the bench depth behind it, plus RealSense
flying pixels in between. Those become streaks along each camera ray. They
are dense enough to survive `_remove_outliers` (20 neighbours, 2σ) and hardly
move the mean, which is why the centroids still agreed. Replay of
`scene_captures/stirrer_white_20260925_113812`:
- cam 2's cube cloud: **17.7 × 9.6 × 11.9 cm**, depth tail to 0.66 m behind a
  cube at 0.47 m.
- cam 3's: **11 × 12.9 × 12 cm**.
- Fused after consensus: **19 × 6 × 12 cm** for a 30 mm cube, with z
  reaching down to the table. That frame happened to pass under 0.35 m; the
  live one did not. So the earlier success was luck, not a regression.

Fix: `ObjectLocalizer._depth_gate` keeps only pixels within the object's
apparent size of the mask's median depth. The size is the 2-98 percentile
pixel box, converted to metres at that median depth, with a 20 mm minimum. A
cup gets a band as deep as it is wide; a small object gets a tight one.
Same stills afterwards:
- cube: cam 2 **3.9 × 4.3 × 3.1 cm**, cam 3 **4.3 × 4.1 × 3.0 cm**, z
  0.071-0.103 (cube only).
- `"clear plastic cup"` (b10_water): 3 cameras identical, cam 3 dropped 80
  of 3,331 points, a tail that made it 2.5 cm too long in x.
- `"white bowl"` (b10_water and bowls_20260924): identical on every camera.

The replay used nominal 848×480 intrinsics (fx = fy = 610); the robomail
`.intr` files are 640-wide and unusable. Tried and rejected: **2 px mask
erosion.** It left cam 2 at 14.5 cm, because the streak pixels are not all
on the outer ring. The live failing frames were not saved, so this is
diagnosed from stills of the same cube, not from that exact run. **Not yet
re-run on the robot.** The replay script is small, so rebuild it rather than
look for it: grounding client + `_depth_to_points` on `cam{N}_depth.png`.
`test_depth_gate_drops_edge_streaks_not_containers` added;
`test_skills_offline.py` 198 pass (the same 2 scoop failures as before),
`test_agents_offline.py` 61 pass.

The measurements below are still the ones to trust if `--exemplars` comes back
on.

## Custom objects: what the exemplar path measured

Text prompting ran out on the printed tools. SAM 3 is open-vocabulary, not
unlimited: `scripts/sweep_prompts.py` spent twenty phrases on the scoop and the
best honest hit was `"scoop"` on 2/4 cameras (`diag_out/stirrer_prompts/` is the
same story for the stirrer), while the phrases that scored *well* —
`"white object"`, 0.95 on 4/4 — were matching the cups. The concept is simply
not in the model, so no wording fixes it.

When `--exemplars` is passed, these objects are matched by **appearance**.
SAM's automatic mask generator segments everything in the frame (no prompt,
class-agnostic), DINOv2 embeds each candidate crop, and the best cosine match
against a reference crop wins. Reference embeddings live in `exemplars/*.npz`.
That flag is not the default as of 2026-09-25; see the note above.

### Registering an object

```bash
source scripts/env.sh
python scripts/capture_scene.py --label stirrer_white

perception_env/bin/python scripts/register_object.py --name stirrer \
    --images-dir scene_captures/stirrer_white_<ts>          # drag a box per camera
```

The service does **not** load `exemplars/` unless started with
`--exemplars exemplars` (`--exemplar-thresh` to tune). Verify with the
existing sweep:

```bash
python scripts/sweep_prompts.py --images-dir scene_captures/<run> \
    --only stirrer --save-overlays diag_out/stirrer_exemplar
```

### Registered so far (2026-09-25)

| Object | Views | Aliases |
| --- | --- | --- |
| `stirrer` | 4 (seated in holder) | — |
| `stirrer holder` | 8 (4 occupied + 4 empty) | `holder`, `tool holder` |
| `scoop` | 4 | `white plastic tool` |

Measured on `scene_captures/stirrer_white_20260925_113812` and
`holder_empty_20260925_120924`: **0.95-1.00 on all four cameras**, margin
0.43-0.72 over the next-best registered object. Leave-one-camera-out (register
from three, query the fourth) gives 0.69-0.85 — the honest number for a viewpoint
with no reference. Cross-object reference similarity: stirrer/holder 0.52,
stirrer/scoop 0.45, holder/scoop 0.34.

### Four things that cost real debugging time

1. **Register what you want to GRASP.** `ObjectLocalizer.get_object_pose` puts
   the grasp at the *mean of the fused mask points*. A first pass registered
   "stirrer" as the white cube **plus** the black cylinder it sits in; it scored
   0.95+ and would have driven the gripper into the middle of the holder. The
   cube is the stirrer, the cylinder is its holder, and they are now two
   objects. A high score only means "this is the shape you showed me".

2. **Register every state.** A holder with the tool in it and an empty holder
   are 0.49-0.83 similar — not interchangeable. The holder carries both because
   it is looked for occupied (before a pick) and empty (to put the stirrer
   back). Use `register_object.py --append`.

3. **Multi-part objects.** A two-tone object is several objects to the mask
   generator: the stirrer's body, the cube's top and the cube's shaded front
   face come back separately, so a whole-tool reference matched none of them
   (0.63 on cam2, head cut off). Merging every adjacent pair blindly gave a lid
   floating above a mug (0.64). What works is `_grow()` — add the neighbour that
   improves similarity to the reference most, repeat, stop when nothing does.
   cam2 0.63 -> 0.95, cam3 0.74 -> 0.99.

4. **Point-grid recall on small objects.** At 32x32 over 848x480 the grid lands
   ~26px apart, wider than the scoop's shank; on one camera that produced half a
   scoop, which genuinely resembles the stirrer cube more than a scoop (0.65 vs
   0.56) and was correctly refused. Raising density everywhere costs 2-3x on
   every frame *and* shifts which candidates seed `_grow` (cam2 scoop
   1.00 -> 0.89), so the service retries **only missed frames** at 48x48
   (`--exemplar-retry-points`). Growth adjacency also had to widen from a fixed
   8px — the two scoop fragments sat 9px apart — to 16px scaled by candidate
   size; similarity gates the merge, so the geometry test can be generous.

### Cost

~4s for the first query on a frame (mask generation), ~0.15s for every further
object on that same frame (candidates and embeddings are cached per image,
bit-packed). A missed frame that triggers the denser retry costs ~13s. A
per-camera miss is not a failed run: localization fuses whatever cameras did find
the object.

---

## Scoop -> dump -> place-back chain (validated 2026-09-25, text prompts only)

One `run_experiment.py` call, four `--skill`/`--params` pairs so the gripper
stays loaded across steps (a second invocation opens a fresh cell with an
empty gripper):

```bash
source scripts/env.sh
scripts/grounding.sh status   # confirm up, and exemplars: [] -- see below

python scripts/run_experiment.py --workspace-min 0.25 -0.40 -0.13 \
  --skill pick_up --params '{"object_name":"scoop","z_offset":0.0,"grasp_force":1.0,"forward_offset":-0.010}' \
  --skill scoop   --params '{"powder_source":"baking soda","tool_offset":[0.051,0.009,0.028],"tool_span":0.0275,"tool_back_reach":0.030,"bowl_length":0.0275,"bowl_width":0.0205,"bowl_depth":0.0115}' \
  --skill dump    --params '{"target_container":"b 10 ml water","container_category":"clear plastic cup","tool_offset":[0.051,0.009,0.028],"bowl_length":0.0275,"bowl_width":0.0205,"bowl_depth":0.0115}' \
  --skill place   --params '{"target_location":"scoop"}'
```

- **`object_name: "scoop"` resolves without exemplars.** `SAM_PROMPT_ALIASES`
  maps it to `"white plastic tool"`, the SAM 3 text prompt validated in the
  2026-09-18 sweep. No `--exemplars` flag needed; see the "unloaded" note above
  for why that flag is off by default now.
- **`tool_offset: [0.051, 0.009, 0.028]`** — x/y measured by `pick_up`'s
  `measure_tool_offset` off THIS grasp (it moves if `forward_offset` changes,
  see below); z is the CAD depth, not the measured one. The cameras look down
  and cannot see the bowl floor, so `measure_tool_offset` reports a lower bound
  there (has read as low as 0.011-0.019m depending on grasp) — always take z
  from the printed scoop's CAD (0.028m for a mid-grip grasp), never from the
  printed offset directly.
- **`forward_offset: -0.010` on the pick** moves the grasp off the crank (the
  one spot on the handle where the cross-section changes and the jaws cannot
  seat flat) without going so far it overshoots the flat grip, which is only
  26mm long.
- **`"target_location": "scoop"` on the final `place`** uses the executor's
  pick-site memory (`SkillsExecutor.pick_sites`, added 2026-09-25): a
  successful `pick_up` records where it grasped the object, and `place` resolves
  a matching name to that site instead of asking vision to find a tool that is
  in the gripper and cannot be on the bench for a camera to see. A name the
  executor has not picked passes through unchanged, so this never masks a real
  scene object.
- `container_category: "clear plastic cup"` on `dump` — required because the
  label-category default is now `"white bowl"` (where the reagents live);
  water needs the clear-cup category explicitly.

### The freeze this chain caused before the exemplar stack was turned off

Running this same chain with `--exemplars` on (DINOv2 + a second SAM resident)
froze the whole desktop, not just the grounding process, partway through step
2's `segment_instances` call. Measured cause, in order ruled out:

1. **Not the shared USB controller.** Real and reproducible in `dmesg` (a
   Realtek HID hub dropping with `error -71` under camera load), but a HID drop
   kills the mouse, not the whole desktop, and the timing did not match.
2. **Not per-instance label reads.** Reverting to one whole-frame VLM call per
   camera was tried and made cross-cup labelling WORSE:
   `scene_captures/ab_water_20260921_102436`, `"a 10 ml water"` / `"b 10 ml
   water"` went from 4/4 + 4/4 (per-instance) to 2/4 + 0/4 (whole-frame), with
   invented labels (`"WEAK BASE"`, `"GLITTER ADD"`) not on the bench. Reverted
   back; per-instance stays default (`LabelResolver.per_instance = True`).
3. **Not batching cameras into the /segment call.** Sending 4, 2, or 1 camera(s)
   per HTTP request all measured the identical **8.90GB peak** — the growth is
   a one-time CUDA/workspace allocation on first use, not a per-frame cost, so
   splitting frames across requests cannot lower it.
4. **The actual cause: host RAM.** This machine has 15GB. The grounding
   service with SAM 3 + DINOv2 + a second SAM resident sat at **5.85GB idle,
   8.90GB peak** after the first segmentation of any kind — a permanent step,
   not a spike that comes back down. With Slack and spare editor windows open,
   `available` was ~3GB; the peak exceeded it and the kernel started paging
   rather than OOM-killing anything, which is what a full desktop freeze looks
   like (no `oom-kill` in `dmesg`, 1.3GB already in swap before the run even
   started). `vm.swappiness=60` (the default) does not help here: the 64GB
   swap file was untouched at the time of the freeze, because the resident set
   was live model weights being paged back in on every inference, not idle
   memory swap could usefully evict.

Fix: `--no-exemplars` (now `scripts/grounding.sh`'s default). Confirmed
`/health` idle at **360MB, 0 swap**; loads the 3.3GB SAM 3 weights lazily on
first `/segment` and settles at **3.2GB resident, 5.2GB GPU, 0 swap** after.
The trade is the stirrer and its holder have no validated text prompt yet (see
above) — this chain does not need them, so it is unaffected.

---

## Instruction → VLM → sim: how to run it (2026-10-02)

The whole loop runs in sim with a live model. An instruction comes in as a
text task or as a photographed sheet; the model plans skill calls; the sim
executes them. Needs `openai_api_key=` in the repo's `.env`. Verification stays
off in sim, because there is no chemistry.

```bash
source scripts/env_dev.sh
# a typed instruction: the whole text goes to the planner
python scripts/run_experiment.py --sim --workspace-min 0.25 -0.40 -0.13 \
  --task "Add one scoop of citric acid to the white paper cup, then stir the cup with the stirring rod. Put the scoop and the stirring rod back where you found them."
# a photographed instruction sheet; --follow-steps passes its steps on too
python scripts/run_experiment.py --sim --workspace-min 0.25 -0.40 -0.13 \
  --instruction-image instructions/citric_acid_stir.png --follow-steps
```

`instructions/citric_acid_stir.png` is a card written for the sim bench. The
booklet's Magic Beaker (pages 12-13) used to be refused in sim for want of red
cabbage powder, water, clear cups and liquids. Since 2026-10-02 the bench has
them, see "The Magic Beaker kit in sim" below:
`--instruction-image instructions/magic_beaker.png --follow-steps`.

**The typed `--task` above is stale since 2026-10-03: the sim bench has no
white paper cup any more** (see the Magic Beaker kit section). The model does
not refuse it. It substitutes a cup without saying so. Connectivity check on
2026-10-07 after pulling `6b49166`, with `--dry-run --no-viewer`, layout seed
902184 (log `agent_run_20261007_162148.json`, run from the scratchpad, not
kept in `experiments/`):
- Run log `models`: `strong_model gpt-4.1`, `cheap_model gpt-4.1-mini`,
  `base_url None` (plain OpenAI), `api_key_present True`. The scene call saw all
  11 sim objects by their inventory names.
- The plan was 7 sub-tasks, and all 7 resolved to valid skill calls with no
  replan. Dump and stir both went to **`clear cup c`**. The planner's own
  `expecting` line reads "the white paper cup (clear cup c)". Nothing was
  flagged as a substitution.
- So a task that names a container the bench lacks is quietly remapped, not
  blocked. To repeat the 2026-10-02 run, name `clear cup a` (what the card
  names now) in the text.

**Measured on 2026-10-02 (live gpt-4.1, layout seed 829181).** Both commands
above ran all 7 planned steps:
1. spoon, scoop citric acid, dump into the paper cup, spoon back;
2. stirrer, stir the paper cup, stirrer back into its holder.

Neither run touched anything but the grasps, and nothing moved more than 3 mm.
Another seed (31337) was clean on the text task too. Getting there took these
fixes:

- **Image instructions lost their steps.** The orchestrator hands the planner
  the parsed goal alone, which is the research design. Given only "prepare a
  citric acid mixture", the planner dumped into the beaker and never stirred.
  `--follow-steps` (opt-in) appends the sheet's steps.
- **`InstructionParser` was pinned to `gpt-4o`** (API shutdown 2026-10-23). It
  now uses `agents.config.strong_model()`. **Still pinned, still to do before
  10-23:** `vision/label_resolver.py` (the real cell's labelled-cup reads),
  `vision/scene_analyzer.py`, and the legacy `task_planner` / `vlm_orchestrator`.
- **The scene agent called the citric acid dish "empty"** in about 1 run in
  4, and the planner then refused the task. The sim labels are blank paper,
  now mostly hidden under the 102 mm dish. The prompt now says a
  reagent-named inventory entry is that container's label. After the change,
  3 of 3 scene calls on the failing layout reported "citric acid".
- **Putting tools back.**
  - The model put the spoon "beside the citric acid", landed it on the dish
    and pushed the dish 11 cm.
  - It put the stirrer "beside the stirrer holder", which dropped it on the
    bench, and the hand hit the beaker.
  - Now the catalog tells it to name the tool itself. The executor also maps
    a tool's alias or its home ("stirrer holder") to the tool's pick site and
    fills its put-back params from `skills/tool_geometry.py` (the stirrer:
    `vertical_insert`, force-probed seat).
- **Stir got pick_up's measured z (0.017) as `tool_length`,** because the
  orchestrator's note said to pass it to "any that takes tool_length". That
  is 64 mm short for the stirrer. The note no longer says so, and the executor
  raises a `tool_length` under 80% of the tool's CAD length (0.081) to CAD.
- **Twice the stir skill call came back as broken JSON,** despite strict
  schema, and the second time blocked the task. `structured_completion` now
  re-asks once, slightly warm.

**Random layouts: tall containers now keep 18 cm from the powder dishes.**
The scooping hand is about 200 mm across its jaws, and the wrist reaches
toward the base. Centre distances measured in sim: 144 mm hit, 145 mm hit,
161 mm hit (link7), 172 mm clear. **The fixed default layout breaks this
rule:** scooping BAKING SODA there drives the hand into the plastic beaker
(144 mm, 1699 contact steps). Every validated chain scooped citric acid, which
is clear. `randomize_layout` also now checks each draw against every other
prop's current spot. 200 of 200 seeds give a clean layout.

**Where Aliyah's repo lives.** `robomail/` is the rumilog submodule (b7b83a0).
Do not clone over it. Aliyah's repo (aliyahreddingdidit/robomail) belongs in
`robomail_Aliyah/`. That path is a committed gitlink to her 4bee1ac with no
`.gitmodules` entry, so `git submodule update` does not fill it, and a fresh
checkout leaves it empty. Clone her repo there by hand. When it is missing, the
offline tests skip the vocabulary bridge group.

On 2026-10-02 her clone was found over `robomail/`. It was moved to
`robomail_Aliyah/` and the submodule was restored. Results after the move:
- `test_skills_offline.py`: 201 passed, plus the 2 old scoop failures. The
  bridge group passes.
- `smoke_test_sim.py`: all 9 groups pass.

## The Magic Beaker kit in sim: props, liquid, chemistry (2026-10-02)

The sim bench (`sim/bench.py default_bench`) holds what the booklet's Magic
Beaker (pages 12-13, `instructions/magic_beaker.png`) needs and nothing else,
laid out the way the real bench is. **Since 2026-10-03 that means seven
containers.** The user asked to keep only what the experiment needs, so the
white paper cup (a leftover distractor) and the separate 50 ml water cup went.
The beaker now starts with the 50 ml.

| Prop | What it is | Measured? |
| --- | --- | --- |
| citric acid / baking soda / red cabbage powder cup | the same 91/102/29/8 mm dish (`_powder_dish`), 18 mm bed | dish yes; red cabbage colour no |
| clear cup a / b, labels `a 10 ml water` / `b 10 ml water` | 10 ml water each, as on the real bench | **47.3 mm tall, 55.5 mm across the outside, measured by the user 2026-10-03.** Wall 1 mm and base 3 mm are not measured. A straight cylinder (53.5 mm inside, 100 ml), so 10 ml stands 4.4 mm deep, a bit more in the real tapered cup. Until 2026-10-03 the sim had 52 x 66 mm cups read off depth (`scene_captures/b10_water_20260925_153459`), where 10 ml was 3.0 mm deep. |
| clear cup c | empty, for the final mix | the same cup |
| plastic beaker, label `50 ml water` | the indicator's 50 ml, there from the start | beaker as before |
| smaller spoon (`small scoop`) | **placeholder**: spoon.stl at 75%, CAD in `tool_geometry.py` from sim | no part exists |
| larger spoon, now also `big scoop` | unchanged | yes |

Water comes pre-measured because `pour` cannot meter: it tips until the level
reaches the rim. That is what the real bench does too.
`instructions/citric_acid_stir.png` now names clear cup A; it used to name the
white paper cup.

**`robochem/sim/lab.py` keeps the books on contents**. It is on by default in
`build_cell`; `film_sim_skill.py` turns it off and keeps its own tally.
- Every scoop's load is tracked by reagent (`powder.ScoopTally`, now multi-bed).
- Powder lands in whatever opening is under the bowl's lowest rim point.
- Liquid runs over a tilted container's lowest rim point once the level surface
  reaches it, and lands in whatever opening is below. A lattice gives the volume
  kept at each tilt.
- Powders dissolve: tau 45 s still, 2 s while a stirrer's tip moves in the liquid.
  Baking soda is capped at 0.13 g/ml of warm water.
- Citric acid (3 eq) and bicarbonate neutralise each other and foam.
- A rough pH (triprotic titration, flattened) colours the red cabbage indicator.
- None of these constants is measured on the kit.

After every skill it prints `[lab]` lines and adds them to the result as
`sim_lab`, for the log only; the planner never sees them. `run_experiment
--sim` prints the end state.

**The scripted Magic Beaker** (`scripts/sim_magic_beaker.py`, default layout; it prints the contact audit and contents). It was 28 steps on 2026-10-02; with the water already in the beaker it is 25:
- Steps: big scoop citric acid into A, baking soda into B; small scoop red
  cabbage into the beaker (water cup into the beaker, 2026-10-02 only); stir A, B, the beaker
  with `to_floor`; beaker 80 deg into A, 90 into B; A and B into C; everything
  put back.
- Outcome: A pH ~1.7-2.0, **red**; B pH 8.3, **blue**; C fizzes 9.7 meq, pH
  5.8-6.2, **purple/magenta**. The booklet says purple.
- Every pour landed in its target; nothing ran onto the table.
- Leftover citric acid in the big scoop fizzed B a little when the same scoop
  took baking soda. That is real.

*The runs below, through seed 4242, were on the 9-container bench of
2026-10-02, which had a water cup and the paper cup.*

**Live, planner-driven (gpt-4.1), fixed layout, 2026-10-02.** Run with
`--instruction-image instructions/magic_beaker.png --follow-steps` (record
`experiments/agent_run_20261002_*`).
- The plan was 36 sub-tasks. All executed with no replan, and every tool and
  cup went back by its own name.
- Contents: A got 0.96 g citric acid, B 1.20 g baking soda (+0.26 g of the
  scoop's leftover citric acid), the beaker 0.28 g red cabbage + 50 ml.
- Pours: beaker into A 26.1 ml, into B 23.9 ml; A into C 30.9 ml, B into C
  33.9 ml.
- C fizzed 10.2 meq and ended at **pH 6.4, purple**. A kept 5 ml, red.
- The only contacts were the stirrer meeting the floor of A and B while
  `to_floor` felt for it. Nothing on the bench moved more than 5 mm.

**Same, random layout seed 4242** (the dishes and clear cups swapped round):
- 34 sub-tasks, all executed, and again only the `to_floor` floor touches.
- The big scoop took only 0.49 g of baking soda here, against 1.20 g on the
  fixed bench. C fizzed 2.5 meq, the acid was left over, and C ended **pH 4.1,
  pink** instead of purple. How much a scoop collects is the outcome's main
  lever.
- The first try of this seed stopped dead after step 30's pour, with no
  traceback and no OOM line visible. Two sims were rendering with EGL at the
  time. The rerun, alone, went through. Watch for it.

```bash
python scripts/run_experiment.py --sim --workspace-min 0.25 -0.40 -0.13 \
  --instruction-image instructions/magic_beaker.png --follow-steps
```

### 2026-10-03: seven containers, and three things trimming them uncovered

- **The layout was redone for seven containers.** Annealed with 2 cm of slack
  on every rule, then centred: each container has 16-27 mm of slack (it was
  4-26).
  - Acid on the left (dish behind cup A), base on the right (dish behind
    cup B), the beaker in the middle, red cabbage behind it on the left, cup C
    at the front left.
  - 200 of 200 random seeds break no rule, keep every container in 3+
    cameras, and move every container (median 133 mm); before, some could not
    move at all.
- **Segmentation was rendered through multisampling.** The IDs at every edge
  were the average of two IDs, which spells a third geom.
  - Usually such a pixel just landed on some unrelated geom. On this bench one
    spelled 355 against a 316-entry table, and MuJoCo's decode raised
    `IndexError` on the first locate.
  - With more geoms the stray pixels had been assigned silently: a clear cup's
    mask picked up a pixel 0.37 m away and was rejected as "includes the table".
  - `SimVision` now renders depth and segmentation with `offsamples=0` and
    decodes the IDs itself, dropping any ID that names no geom. RGB for the VLM
    keeps antialiasing on a second renderer. The decode matched MuJoCo's own
    pixel for pixel wherever MuJoCo's did not crash.
  - 0 stray pixels per camera now.
- **The scoop's yield hangs on the tool offset's x.**
  - The crisper depth moved the spoon grasp 2.8 mm toward the bowl, and the
    big scoop fell from 1.42 to 0.41 ml at every dish position tried.
  - Passing x by hand at the default dish: 25.7 mm (CAD) gave 0.40 ml; 23.5
    gave 0.68; 21.5 (the truth) 1.24; 19.5 1.83. **2 mm is a factor of 2-3.**
  - pick_up's own x (median of the bowl end) was 29.2, 7.7 mm off, so the
    planner, copying it, scooped 0.05-0.07 g into A.
  - pick_up now also reports `tool_extent_x`, the cloud's [1st, 99th]
    percentile along the tool x.
  - For a known tool the executor sets x = the span's middle +
    `span_mid_to_bowl` (spoon.stl: 21.05 mm; smaller spoon 15.8). y and z
    come from CAD. This is used when no offset is given, or when the given one
    is pick_up's own suggestion copied over; a value passed on purpose (the
    bench's [0.051, ...]) is kept.
  - The far edge alone did not work: the bowl's tip is thinly sampled, and its
    98th percentile fell 5 mm short.
  - Measured: 19.6 vs 21.5 mm (larger), 15.3-16.5 vs 16.4-16.5 (smaller). Every
    scoop filled: 1.83 ml big, 0.77 small. The error is on the deep side, about
    1.5 mm closer to the floor than the 3 mm gap.
  - **On the robot this changes planner-driven scoops whenever pick_up ran in
    the same session.** Check the first one.
- **Dump can't hold the bowl still close in.**
  - A cup at x <= 0.257 m failed or drifted 16-18 mm (cup C's spot at x 0.268:
    6.1 mm). From x 0.276 it held within 0.4 mm, left or right, at every angle
    from -50 to +50.
  - New rule: `LAYOUT_MIN_X` 0.28 for every container.
- **The planner tipped cup A only 80 deg into C**, taking "80 for the first of
  two" from the pour note. That wording was about splitting one container. Now
  the note says: 90 for any pour that should empty the source, about 80 only to
  pour part and keep the rest.

**Validated on the seven-container bench (2026-10-03), final code:**
- `smoke_test_sim.py`: 10/10.
- `test_skills_offline.py`: 220 passed, plus the 2 old scoop failures.
- `test_agents_offline.py`: 61/61.
- `scripts/sim_magic_beaker.py` (25 steps, no floor or offset hints):
  - A got 1.33 g citric acid, B 1.19 g baking soda, the beaker 0.28 g red
    cabbage.
  - C ended at pH 5.1, magenta.
  - The only contacts were the `to_floor` floor touches.
- Scoop into and dump out of every container: every big scoop full
  (1.47-1.83 ml), no contact.
- Live, seed 777: 31 sub-tasks, no replan.
  - Beaker 80 into A, 90 into B; A and B into C.
  - C fizzed 8.5 meq and ended at pH 5.1, magenta.
- Live, fixed layout: everything executed, but **the planner tipped the
  beaker 90 into A for "pour some indicator"**. All 50 ml went to A and B got
  none.
  - The reworded pour note did not settle it. The same sheet gave 80 in the
    seed-777 run and 90 here. `pour` cannot meter, and the model's choice of
    angle varies run to run.
  - **Fixed in the orchestrator, deterministically** (`POUR_KEEP_SOME_DEG`).
    Before a pour runs, it looks down the plan. If the held container pours
    again before any later sub-task puts something down or picks something up,
    `pour_angle` is capped at 80. The change is noted as `[adjusted]` and in the
    step record's `adjusted`.
  - Why 80: at a given tilt a container keeps what lies below its rim whatever
    it held before, ~24 ml for the beaker at 80 (the sim's geometry). The
    sheet gives no amounts ("pour some"), so any split works as long as B gets
    some.
  - A container that pours only once (A or B into C) still goes to 90.
  - On the robot, liquid clinging to the wall leaves a little more behind,
    which is the safe side.
  - `test_agents_offline.py`: 66/66, including this case.
  - First live check, fixed layout, 2 runs:
    - one planned 80 then 90 itself (A 26.1 ml, B 23.9 ml; C pH 5.4), so the
      guard had nothing to do;
    - the other died on a different fault (below).
- **The skill-call agent wrote `","` for `pour_angle`** (twice that day). The
  value went through as a string, and pour died converting it.
  - `coerce_params` now checks every value against the catalog's kind.
    "90" becomes 90.0. An optional value that is not its kind is dropped (the
    skill's default applies) and printed; a required one is a planning failure.
  - On the same run, the replan's pour call came back as cut-off JSON twice
    and blocked the task. `structured_completion` now re-asks twice (at
    temperature 0.3, then 0.6) instead of once.
  - `test_agents_offline.py`: 69/69.
  - With both fixes, two live runs (fixed layout, and seed 4242) went
    through: 31 sub-tasks each, no replan.
    - Beaker 80 into A (26.1 ml), 90 into B (23.9 ml).
    - A at 80 into C (32.4 ml; 3.7 ml left in A, red). B at 90 into C (33.9 ml).
    - C ended at pH 5.4, magenta.
    - The only contacts were the `to_floor` floor touches.
    - The planner chose 80 itself both times, so the guard did not have to
      act. The offline test covers the case where it must.
  - The same run also passed `tool_offset` to pour. It was rejected and the
    replan carried on to the end (9 sub-tasks), as the new replan rule asks.
- **With the measured 47.3 x 55.5 mm cups** (same day):
  - Smoke 10/10. The scripted chain was clean: beaker into A 26.1 ml, into B
    23.9; A into C 36.1, B into C 33.9; C at pH 5.1.
  - The dump drift stayed at 0.1-0.2 mm at the x = 0.28 boundary (5 spots), so
    the rule holds for the shorter cup.
  - The live fixed-layout run **again tipped the beaker 90 into A** ("pour
    some" read as all). A malformed pour parameter (`','` for a number) was
    replanned around. That makes 2 of 3 fixed-layout runs on this sheet; the
    pour-amount question is open.
- **Grasp slip is not tested by the sim.** The default magnet grasp cannot
  slip.
  - With `--sim-grasp-mode physics`, the fingers passed through a clear cup's
    0.8 mm wall: closed to 36 mm on a 66 mm cup and lifted nothing.
  - The beaker, which the robot pours fine, slid out during the tip.
  - That mode is not calibrated. Whether a clear cup can be picked and tipped
    to 90 deg without crushing or slipping is a bench question, still to
    answer.

### Pour keeps the held cup's lip just over the target (2026-10-03)

The user saw cup-to-cup pours as far too high and too far forward. Measured
during the old pour (A into C, the beaker into A):
- the lip (the held cup's lowest rim point, where the liquid leaves) was
  **155-185 mm above the target's rim**, over its centre;
- the cup's body hung out beyond the target, away from the base.

The old site is the fixed one tuned on the robot for beaker into paper cup:
target centroid, +0.05 lean shift, -0.08 forward offset, TCP 0.15 m over the
target's top, +2.5 mm per 10 deg.

**New path** (`PourSkill._pour_over_lip`). It is used whenever the held cup's
shape is known; otherwise pour falls back to the fixed site.
- **Where the shape comes from.** `pick_up` now reports the object's top and
  bottom z (1st/99th percentile) and radius. The executor turns them into
  `source_top_above_tcp`, `source_height` and `source_radius` and fills them
  into pour; the bottom is the table when `table_z` is set.
- **Where the lip goes.** Pour models the held cup as rings in the tool frame.
  At each 10 deg tip step it puts the lip `lip_clearance` (15 mm) over the
  target's measured rim, `lip_inset` (0.4) of the inside radius toward the
  base from its centre.
- **How high the cup rides.** The TCP is raised wherever needed so that every
  point of the cup stays `body_clearance` (10 mm) over the rim height. An
  upright cup's bottom is lower than its lip, so the cup starts higher and
  comes down as it tips.
- **Approach and finish.** The cup arrives 6 cm over the start, goes down,
  tips step by step, holds, then is righted in place 4 cm up before going home.

Measured in sim, after:

| Pour | Lip over the rim | Lip from the target centre | Lowest point of the held cup over the rim |
| --- | --- | --- | --- |
| A into C, to 90 | 57 mm at the start, 19 mm at 87 deg | 11-13 mm toward the base | 11-17 mm |
| beaker into A, to 80 | 104 mm at the start, 35 mm at 77 deg | 11-14 mm toward the base | 11-14 mm |

The beaker's lip stays higher because its bottom edge, 97 mm away, swings
lower than the lip until late in the tip. The same liquid went in as before:
10.0 ml and 26.1 ml.

**The grasp height mattered too.** The bench-validated `z_offset` 0.02 for the
beaker puts the TCP 7 mm ABOVE a 47 mm cup's rim, so the pads, which reach
8.9 mm past the TCP, held its top 2 mm. With pick_up's default (z_offset 0)
the rim is 13 mm above the TCP. `sim_magic_beaker.py` now picks cups on the
defaults, as the planner does.

**On the robot:** after a pick_up in the same session, pour now takes the new
path. It has not run on the robot; the fixed site it replaces was validated
there for beaker into paper cup.

`test_skills_offline.py`: 227 passed, plus the 2 old scoop failures. The new
`pour: lip over the target` group covers the final lip at 15 mm, never under
it, the lip's spot, the descent, and the fallback.

### What the arm actually sweeps, and the layout rules made from it

Measured from the links' collision geometry in sim, in the target's radial
frame. The scratch scripts that did this were not kept. They sampled every arm
link's collision vertices below 0.13 m every 25 steps of a dump, pour or scoop
into each target.

| Motion | Arm below 0.10 m | Arm below 0.13 m |
| --- | --- | --- |
| dump into a 52 mm cup | ahead -0.05..+0.17, aside -0.06..+0.12 | -0.09..+0.27, -0.13..+0.15 (link6/7 reach out) |
| dump into the 95 mm beaker | none | -0.04..+0.14, +-0.03 |
| scoop a dish | -0.08..+0.14, +-0.13 | -0.08..+0.14, +-0.13 |
| pour (any) | none | none |

Nothing comes lower than ~26 mm above the target's rim. The rules in
`bench._conflicts` (`layout_violations`) come from this table:
- `DUMP_SWEEP` keep-out boxes by obstacle height above the target rim; nothing
  within 15 mm of the rim height is constrained.
- Tall things are kept 0.18 m from dishes (the old rule, now confirmed by the
  scoop sweep).
- Bodies are 3 cm apart, labels must not overlap, nothing within 12 cm of the
  holder.
- A tall container is at least 0.38 m from the base. The paper cup at 0.358 m
  could not be reached by dump after a scoop on the far side (stopped 22 mm
  short); at 0.38 m it worked.

The layout was annealed under these rules, then each container was moved to
the middle of the spot it may occupy, with at least 3 cameras seeing it. That
left 4-26 mm of slack per container. The rest of this note does not need the
scratch scripts: `layout_violations` and the shuffle are in `bench.py`.

`randomize_layout` now first **swaps containers of the same body** (the three
dishes, the four clear cups), then jitters each within 6 cm under the same
rules plus a 3-camera check. Jitter alone barely moved anything with the full
kit on the bench.
- 200 of 200 seeds break no rule and keep every container in 3+ cameras.
- Median move is 142 mm.

### Failures that cost time, and what was changed

- **My contact audit was silently off.** `kit_chain.py` wrapped
  `cell.arm._step` and then restarted the lab, which put the class method back.
  That gave "0 contacts" for runs that had them. The audit must patch
  `SimFrankaArm._step` on the class before `build_cell`.
- **Corridor too short.** With the first layout, dumping into cup B drove
  link6 into the seated stirrer, 0.20 m ahead and 0.096 aside. That is outside
  the 0.22 x 0.09 corridor I had guessed, so the sweep was measured instead.
- **A measured tool_offset pointing at the wrong end.** pick_up's
  `measure_tool_offset` took the handle end as the bowl: x was -30 mm against
  CAD +25.7. The grasp sat 16 mm toward the bowl, after the spoon moved to
  (0.62, -0.03). The live VLM run passed it to scoop and dump. The hand flung
  two dishes 2.3 m and hit the beaker and the water cup. `_fill_tool_geometry`
  now discards a measured offset whose x points the other way from the CAD, or
  that is more than 20 mm to one side. The bench-validated [0.051, 0.009, ...]
  is still kept, z raised.
- **`to_floor` stir.** A rim-relative `stir_depth` (0.03) never reaches 10 ml
  in a 52 mm cup: the tip stopped 18 mm above the water. On the real robot,
  `stir_depth` 0.02 in `b 10 ml water` probably did not reach it either.
  `stir(to_floor=true)` feels down to the floor (1 mm steps, 4 mm back-off) and
  is refused without a force reading. Getting it clean took three fixes:
  - the rod went **through** the 3 mm base, because default soft contact let it
    sink past half the thickness; container bases and the rod now use the
    printed parts' stiff `solref`;
  - the fingers (8.9 mm past the TCP) and the stirrer head brushed the rim:
    pick_up holds the head 6.8 mm low, so it hangs ~22 mm under the TCP. Stir
    now keeps the TCP `hand_clearance` 30 mm above the rim, whatever depth was
    asked;
  - the rod (66 mm) cannot reach the floor of the 95 mm beaker with the hand
    clear, so the beaker is stirred above its 50 ml (`hand_limited`). The
    indicator still dissolves unstirred in the sim. Expect the same on the
    robot.
- **The planner set things down "beside" others.** The water cup went onto the
  beaker's spot, and the beaker onto cup B and then into cup A. Cup A went
  over and 34 ml ran onto the table. Fixes:
  - `place` now puts a held object that was picked from the bench back where
    it came from whenever it is asked to go beside something else;
    coordinates and `on_top` pass;
  - the catalog says to name the object itself.
- **A replan ended the run early.** After that failed place, the corrective
  plan was the place alone, and the orchestrator reported success with the
  final pours never run. The replan prompt now says the plan replaces
  everything that has not run, so it must carry on to the goal.
- **The scene agent called water cups empty and dropped objects.** It got the
  inventory as a flat list, with "clear cup a" and "a 10 ml water" as two
  names. `SimVision.inventory_notes` now gives one line per object, with its
  label and other names ("larger spoon -- also called big scoop"). The scene
  agent also now gets two opposing views (cams 2 and 4), not 2 and 3 from the
  same side. Next dry run: "clear cup a | a 10 ml water", and the big scoop was
  used for citric acid and baking soda.
- **The planner tipped the beaker 40 deg to "pour some".** That pours nothing.
  The pour note now says liquid leaves only once the level reaches the rim:
  about 80 for "some", 90 for the rest. The next plan used 80 then 90.
- **InstructionParser misread step 7** as "into the beaker" in 2 of 3 reads.
  At temperature 0, with a line asking to keep each step's containers, it read
  "the empty clear cup" in 3 of 3.
- `MAX_SUBTASKS` 24 -> 40: the plan is 28-34 sub-tasks.
- **The big scoop came up empty in every planner-driven run.** The cause was
  the old open item, the floor estimate. `base_z` (3rd percentile of the cloud)
  reads 3.0 mm for a dish standing on z=0, even with no depth noise. The
  beaker reads 6.1 mm and the cups 2.3-5.3. The bottom edge is only seen at a
  grazing angle, so that percentile lands on the wall; `top_z` is within 1 mm.
  The floor came out 3 mm high, and the larger spoon's mouth stayed above the
  bed: 0.00 ml. The scripted chains never hit this because they pass
  `container_floor_z`.
  - Fix: the executor config takes `table_z`. When it is set and the container
    stands on it (base_z - table_z within -5..+12 mm), scoop takes the inside
    floor as `table_z + floor_thickness`. `build_cell` sets 0.0.
  - Planner-style scoops (no floor hint, a bad measured offset) then carried
    1.42 ml citric acid, 1.43 ml baking soda and a full 0.77 ml small scoop.
  - **On the robot nothing changes until `table_z` is configured.** The cage's
    table sits at about z = -0.013 to -0.017: the ring around the dish and the
    B cup in `scene_captures/b10_water_20260925_153459`, cams 2-5.
- **A DNS hiccup killed two runs**: `openai.APIConnectionError` escaped every
  handler. `llm_client._create` now retries transient errors after 3, 10, 30
  and 60 s, then raises `LLMResponseError`, so the stage reports blocked
  instead of crashing.
- **On random layout seed 4242 the scene agent described 6 of 13 objects.**
  The planner took the citric acid dish and the beaker to be missing and
  refused the task. `comprehend_scene` now appends every inventory object the
  agent left out, with its label as contents, marked as such. The re-run listed
  13 and planned 34 sub-tasks.
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

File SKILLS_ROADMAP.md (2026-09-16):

# Skills roadmap — what the agent stack needs, and how to build it

Last updated: 2026-09-16

Two halves of this project are converging:

- **`robochem/`** (this repo's root) — the real Franka + RealSense manipulation
  stack. `pick_up` and `pour` are bench-validated; see [`progress.md`](progress.md).
- **[`robomail_Aliyah/`](robomail_Aliyah/)** — the PLATO-derived agent pipeline
  (goal extraction → planning → affordance → step planning → verification →
  logging). It runs end to end against live models, but **its skill executor is
  a stub**: `robomail_Aliyah/skills/executor.py` fakes every success from
  `FAKE_SUCCESS_RATE` and the arm never moves.

This document answers: *which skills does the agent stack expect, how do we
build them to the standard `pick_up`/`pour` set, and how do the two halves
eventually join up.*

---

## 1. The contract: six actions, closed and exhaustive

`robomail_Aliyah/agents/action_vocabulary.py` defines a **closed** enum. The
Step Planner is constrained to it by JSON schema and *cannot invent an action*;
anything it cannot express raises `InfeasibleStep`, which is logged and fed back
into replanning. So this list is the complete set of skills the agent side will
ever ask for.

| Action | Semantics (verbatim from their prompt block) | robochem skill | Status |
| --- | --- | --- | --- |
| `PICKUP` | Grasp an object (tool or container) and lift it | `pick_up` | **Bench-validated** |
| `POUR` | Tip a held container so its contents flow into a target | `pour` | **Bench-validated** |
| `PLACE` | Set a held object down and release, freeing the gripper | `place` | **Bench-validated 2026-09-11** |
| `SCOOP` | Use a held scoop to transfer a measured quantity of powder | `scoop` | **Bench-tuned 2026-09-16** (4 runs — see §3) |
| `STIR` | Agitate a container's contents with a held implement | `stir` | **Rewritten, needs bench time** |
| `PIPETTE_DISPENSE` | Use a held pipette to **draw and release** a small volume | `dispense` | **Rewritten, needs bench time** |

**So: four skills were missing in practice.** All four existed as files, but
none of them had been through the hardening that `pick_up` and `pour` went
through — they used fire-and-forget motion, misread object height, and returned
`success=True` regardless of what the arm did. All four are now rewritten
(§3–§4) and pass 79 offline checks. `place` and `scoop` have since been
bench-validated; `stir` and `dispense` have not yet run on the robot.

`PLACE` deserves emphasis. The robot profile
(`robomail_Aliyah/config/robot_profile.py`) states *"Only ONE object may be held
at any moment. To use a second object, the first must be PLACEd down first"*,
and the planner is directed to *"insert an explicit PLACE before any step that
needs a different tool."* Every multi-reagent plan is therefore
PICKUP → use → PLACE → PICKUP → use → PLACE. **Without a reliable `place`, no
plan longer than one tool can run**, regardless of how good pick and pour are.

### Not in the vocabulary

Our registry also has `move_to`, `tilt`, `wait`, `open_gripper`/`close_gripper`,
`analyze_scene`, `locate_object`, `check_container`. The agent stack will never
call these — they are useful for our own VLM orchestrator and for bench
debugging, and they do not need the same hardening.

---

## 2. The hardening playbook

Distilled from what actually made `pick_up` and `pour` work. Each pattern below
is there because its absence caused a specific failure. Apply all of them to any
new skill.

### P1. `reset_joints` before every scan

Not a hardcoded XYZ park. From an arbitrary pose a cartesian retract is often
unreachable, and scanning with the arm over the table occludes the object and
pollutes the fused cloud. Joint-space home is always reachable.

Safe while holding something — `pour` does exactly this with the beaker in the
gripper. Helper: `BaseSkill.clear_cameras(params, tag=...)`, honouring
`reset_before_scan` (default `True`) and `retract_xyz` as the escape hatch.

### P2. Measure the object in the world frame, never from `dimensions[2]`

`vision.get_object_dimensions()` returns **PCA extents sorted descending**, so
`dimensions[2]` is the object's *smallest* extent. For an upright beaker
(120 mm tall, 40 mm across) that is the **diameter**. Every skill that did
`target_pos[2] + dims[2]` to find the rim was aiming ~80 mm low, straight into
the cup.

Use `BaseSkill.locate_container(name)`, which returns from the raw cloud:

| Key | Meaning |
| --- | --- |
| `top_z` | 97th-percentile Z — the rim. Percentile, not `max`, so a few depth outliers do not set the height |
| `base_z`, `height` | 3rd-percentile Z, and the difference |
| `rim_center` | **Median XY of the top 15 mm band.** Cage coverage is one-sided, so the fused cloud leans toward whichever cameras saw the object and the full-cloud centroid sits off the opening |
| `rim_radius` | 90th-percentile radial distance within that band |

### P3. Every motion is verified, or it did not happen

`move_to_position` was fire-and-forget: it issued `goto_pose` and returned
`True` unconditionally. That is the single largest source of false successes in
the old skills. It now takes `reach_tol` and re-reads the pose; `goto_pose_rigid`
+ `reached()` is the position-and-orientation version.

Tolerances are not uniform, and the reason matters:

| Phase | Tolerance | Why |
| --- | --- | --- |
| Free-space hover | 50 mm | Coarse; only gross unreachability matters |
| Descent into/above a container | 25–30 mm | Tight — this is where being high means dropping or missing |
| Contact motion (digging powder) | 50 mm | Loose — the medium resists, so the arm legitimately stops short |
| Circle waypoints while stirring | 50 mm | Loose — the tool is in fluid; only a jam matters |

### P4. Fail loudly rather than succeeding quietly

`pour`'s hardest-won lesson: it used to report `success=True` at a measured 39°
while having commanded 90°. Now the tip is measured after every step and a
shortfall fails the skill.

Generalise: **measure the thing the skill exists to achieve.** `scoop`'s bite
tilt is measured before it commits to the powder — pushing level collects
nothing, so an unverified tilt is not a scoop worth attempting.

**But know what your measurement cannot see.** `tool_tip_deg()` is an `arccos`
magnitude: it reports *how far* from vertical, never *which way*. A tilt in
exactly the wrong direction passes it cleanly. `scoop` shipped that bug to the
bench twice. Where direction matters, check a signed quantity — `pour` checks
`lean·dir` against its intended lean vector, which is the pattern to copy.

### P5. Retry a lagging step before giving up

frankapy often needs a second, longer `goto_pose` before the wrist tracks a
commanded orientation. `pour` retries each tip step up to `step_retries` times
with a lengthening duration; `scoop` does the same for its bite tilt.

Retry the **remaining** delta, not the original command —
`rotate_about_tool_axis` is relative, so re-commanding the full angle stacks
rotations and overshoots.

Better still, where a *sequence* of orientations is needed, compute them
analytically against a fixed reference and command absolute targets — see
`scoop.tool_y_delta` and its use across the push. Absolute targets are
idempotent under retry; relative nudges are not.

### P6. Tool-frame rotation for anything gripper-relative

`rotate_wrist` left-multiplies (base frame); `rotate_about_tool_axis`
right-multiplies (tool frame). For any tip that must keep the jaws
table-parallel — pouring, lifting a scoop bowl — the tool axis is the correct
one. The base-frame version rolls the bowl over.

### P7. `use_impedance=False` for orientation, `True` for contact

`pour` only started tracking commanded orientation once it stopped using the
impedance controller, which quietly settles tens of degrees short.
`goto_pose_rigid` defaults to `use_impedance=False` for that reason. Invert it
for contact-rich motion: `scoop`'s dig and drag pass `use_impedance=True`,
because yielding to the powder bed is the desired behaviour.

### P8. Gripper width is the only grasp sensor — use it constantly

Soft paper cups give no useful contact force, so `grasp=True` force-limited
closing just keeps squeezing and crushes them. `pick_up` closes to
*measured diameter − squeeze* with `grasp=False` (a position command) instead.

Every skill after `pick_up` runs with something already held, and the commonest
silent failure is that it was dropped three motions ago while the skill happily
reported success. Record the width at skill start and re-check it with
`check_still_holding()` **before, during and after** the motion — `stir` checks
once per revolution.

Never call `open_gripper()` to relax a squeeze: it opens to 80 mm and drops the
tool. Command the held width back instead.

### P9. Clamp geometry to what was measured

A 15 mm stir circle in a 12 mm-radius cup scrapes the wall and tips it over; a
50 mm scoop drag in a 35 mm tub rams the far wall and stalls the arm. Clamp
against `rim_radius` and refuse when there is genuinely no room, rather than
attempting it.

### P10. `clear_cache()` after the scene changes

The localizer only reads from its cache. After any pick, place, pour or scoop
the cached segmentation is stale and the next skill will act on where the object
*used to be*.

### P11. Blocking waypoints, not a command stream

`stir` previously issued non-blocking `goto_pose` calls in a 50 Hz loop.
frankapy treats each `goto_pose` as a new *skill*, so that pattern starts and
cancels hundreds of skills a second: the arm judders, barely tracks the circle,
and any reach check is meaningless. Walk a modest number of blocking waypoints
instead — slower, but it is motion that actually happens and can be verified.

### P12. Say what you did not measure

`scoop` returns `quantity_measured: False`; `dispense` returns
`volume_measured: False`. Nothing weighs the powder or meters the drops — the
quantity is nominal, set by dig depth and drag length. The robot profile already
concedes this (*"quantities are metered by scoop or pipette"*), and the trial
log should not imply a precision that does not exist.

---

## 3. What each new skill does

### `place` — [`robochem/skills/place.py`](robochem/skills/place.py)

Record held width → clear cameras → scan → measure support surface → hover →
descend (verified) → open → **confirm release** → retract → clear cache.

- **The gripper is never opened from a pose that was not reached.** If the
  descent stops short the skill goes back up, keeps hold, and returns
  `still_holding: True` so the caller knows the object is still in the gripper.
- Defaults to placing *beside* a located target, not on top of it — placing onto
  a container is almost never what a chemistry step wants. `on_top: true` stacks.
- Accepts explicit `[x, y]` or `[x, y, z]` coordinates and then skips the scan
  entirely. This is the path the agent bridge uses for "put the scoop back".

### `stir` — [`robochem/skills/stir.py`](robochem/skills/stir.py)

Clear cameras → scan → clamp radius to the opening → flatten wrist → hover →
descend to immersion depth → walk N revolutions of discrete waypoints → lift.

- Radius clamped to `rim_radius − wall_clearance`; refuses below 3 mm of usable
  radius rather than scraping.
- Grasp re-checked once per revolution; a mid-stir drop aborts instead of
  stirring with an empty gripper for the remaining revolutions.
- Reports `revolutions_completed` so a partial stir is visible in the log.

### `scoop` — [`robochem/skills/scoop.py`](robochem/skills/scoop.py)

Clear cameras → scan → clamp stroke to the opening → hover level (stiff) →
**tilt forward and verify** → plunge in while advancing (tilted, compliant) →
**push away from the base, rolling back to level over the last stretch**
(compliant waypoints) → lift level (stiff).

This one took four hardware runs to get right, and every correction is worth
recording because none of them were visible offline.

**Run 1 — the tilt was in the wrong place.** The original design dragged level
and only tilted *afterwards*, to retain the powder for the lift. That plows the
powder flat instead of collecting it. A scoop has to bite in at an angle before
it moves through the medium, the way pour tips toward its site before liquid
can flow. Moved the tilt ahead of the stroke.

**Run 2 — the tilt direction was backwards, and nothing could have caught it.**
`tool_tip_deg()` measures tilt *magnitude* from vertical via `arccos(-R[2,2])`,
which is always ≥ 0. It cannot distinguish "tilted forward" from "tilted the
wrong way" — only how far from vertical. So the verification reported "achieved
30° of 30° commanded" as a clean success while the wrist leaned the opposite
way. Fixed by negating the angle into `rotate_about_tool_axis`. **This blind
spot applies to any skill that verifies a tool-axis rotation by magnitude** —
pour avoids it by construction, because it tips toward a computed lean vector
and checks `lean·dir`, not a bare angle.

**Run 2 also — the plunge had no forward component.** It descended straight
down and only then started moving. Real digging is already moving into the
medium as it enters. Added `dig_advance`: the entry stroke carries travel.

**Run 3 — the push disappeared.** `dig_advance` was subtracted out of a total
`scoop_distance`, so passing `scoop_distance == dig_advance` silently produced
a zero-length push. Replaced the derived arithmetic with two independent
distances, `dig_advance` and `drag_distance`, because a parameter that can
silently zero out another one is a bad parameter. `scoop_distance` is now
rejected with a message naming its replacements rather than being ignored.

**Run 4 — direction, and the un-tilt belongs inside the push.** Two changes:

- The stroke now pushes **away from the robot base (+X)**, not toward it. (The
  earlier note here claiming toward-base was needed for reach was wrong for
  this motion — that constraint came from `pour`, where the payload is a full
  container at arm's length, not a scoop inside a cup.)
- The roll back to level happens **during** the push, blended across the last
  `untilt_over` metres, rather than as a separate step after the motion stops.
  Closing the bowl over the powder while it is still moving is what keeps the
  load on; stopping and then flicking upright drops it back in the cup.

**Run 5 — the push is continuous, not subdivided.** The first version of the
blend walked eight discrete waypoints and visibly stepped, because each one
decelerated to a stop. frankapy's `goto_pose` is *already* a min-jerk
interpolation of translation **and** orientation, so subdivision buys nothing
here. The push is now two `goto_pose` calls:

| Segment | Motion | Why two, not one |
| --- | --- | --- |
| A | translate `drag_distance − untilt_over` at the full bite angle | a single min-jerk segment interpolates orientation monotonically end-to-end, so it cannot hold an angle and *then* roll off |
| B | translate the last `untilt_over` while rotating to level | |

Setting `untilt_over == drag_distance` collapses this to one unbroken motion
that rolls level across the whole push. Segment durations split proportionally
to distance out of `push_seconds`.

Note this does **not** contradict P11 (stir's blocking waypoints). That lesson
is about a 50 Hz *non-blocking* stream, where frankapy starts and cancels
hundreds of skills a second. A handful of blocking min-jerk segments is the
opposite situation — and where the motion should read as continuous, fewer is
better.

The target orientations are computed analytically — `level_rotation @
tool_y_delta(-angle)` — rather than by issuing relative nudges and hoping they
compose. The final target is exactly `level_rotation`, so the stroke ends level
by construction rather than by a convergence loop.

| Parameter | Default | Role |
| --- | --- | --- |
| `dig_advance` | 20 mm | Forward travel during the tilted plunge |
| `drag_distance` | 40 mm | The push, away from the base |
| `untilt_over` | 20 mm | Tail of the push across which tilt → level |
| `dig_tilt_deg` | 30° | Bite angle (direction corrected run 2) |
| `push_seconds` | 3.0 s | Duration of the push, split across its segments by distance |
| `wall_clearance` | 10 mm | Lowered from 15 mm — it was clamping strokes that fit |

The whole stroke (`dig_advance + drag_distance`) is clamped to the measured
opening, scaling both parts together so their ratio survives. Dig depth is
measured from the top of the cloud *inside* the container, which for a
part-full tub is the powder surface, not the rim.

**Still not confirmed**: whether 30° is the right bite angle, and whether the
quantity collected is repeatable. Nothing weighs the scoop — `quantity_measured`
is `False` for a reason.

### `dispense` — [`robochem/skills/dispense.py`](robochem/skills/dispense.py)

Three modes, because `PIPETTE_DISPENSE`'s stated semantics are "draw **and**
release":

| Mode | Behaviour |
| --- | --- |
| `dispense` (default) | Squeeze/release pulses with the tip above the target rim |
| `aspirate` | Squeeze **in air**, lower the tip into the source, release to draw in |
| `transfer` | `aspirate` from `source_container`, then `dispense` into `target_container` |

- Squeezing before entering the liquid is the whole point of the aspirate
  ordering — squeeze while submerged and the air is blown into the source.
- Squeeze depth is floored at `min_width_fraction` (0.55) of the held width, so
  no squeeze can crush the barrel or pop the pipette out of the jaws.
- The tip stays *above* the target rim while dispensing; dipping it in would
  contaminate the pipette and wick liquid back out.

---

## 4. Bench validation — the order to do it in

None of the four has touched hardware. Offline first, then the robot.

```bash
# No robot, no cameras. 57 checks on geometry, failure paths and the bridge.
perception_env/bin/python scripts/test_skills_offline.py
```

Then, with the arm and grounding service up (see [`progress.md`](progress.md)):

```bash
source scripts/env.sh
perception_env/bin/python perception_service/grounding_service.py \
  --backend sam3 --model weights/sam3.pt   # separate terminal
```

**Step 1 — `place`, because everything else depends on it.** Nothing is held
yet, so pick first:

```bash
python scripts/run_experiment.py --skill pick_up \
  --params '{"object_name":"plastic beaker","z_offset":0.02,"squeeze":0.013}'
python scripts/run_experiment.py --skill place \
  --params '{"target_location":[0.45,-0.15,0.02]}'
```

Start with explicit coordinates (no scan in the loop), then try
`{"target_location":"white paper cup"}` to exercise the beside-a-target path.

**Step 2 — `stir`.** Needs a stirrer the gripper can hold. Start shallow and
slow in a wide container:

```bash
python scripts/run_experiment.py --skill pick_up --params '{"object_name":"stirring rod"}'
python scripts/run_experiment.py --skill stir \
  --params '{"target_container":"white paper cup","revolutions":1,"stir_depth":0.02,"seconds_per_waypoint":1.0}'
```

**Step 3 — `dispense`.** Dry run first (`num_drops: 1`, empty pipette) to see
whether the squeeze travel actually deforms the bulb without losing the grasp.
Tune `squeeze_amount` upward from 3 mm only as far as the grasp survives.

**Step 4 — `scoop`.** Last, because it is the most contact-heavy. Use a shallow
open tub, not a deep one.

### The parameter you must measure first: `tool_length`

`stir`, `scoop` and `dispense` all default `tool_length` to **0.0**, which means
the arm commands the *gripper*, not the tool tip, to the target depth. That is
correct only for a zero-length tool.

**Measure the distance from the gripper TCP to the working end of each tool and
pass it.** Left at 0, a 90 mm stirrer will be driven 90 mm too deep — through
the bottom of the cup.

### Other values that need bench numbers

| Parameter | Skill | Default | Note |
| --- | --- | --- | --- |
| `wall_clearance` | `stir` | 12 mm | Conservative. A 13 mm-radius cup leaves only 1 mm of usable radius and the skill refuses — lower it once the stirrer's real width is known |
| `squeeze_amount` | `dispense` | 3 mm | Enough to deform a bulb? Unknown until tried |
| `scoop_depth` | `scoop` | 15 mm | Nominal; with `dig_advance`/`drag_distance` it sets the quantity, which nothing measures |
| `release_clearance` | `place` | 20 mm | Soft cups may need more; a rigid beaker less |

---

## 5. Integrating with `robomail_Aliyah`

### What is already built

[`robochem/integration/plato_bridge.py`](robochem/integration/plato_bridge.py)
— `RoboChemExecutor` is a drop-in replacement for their stub executor:

```python
from robochem.integration.plato_bridge import RoboChemExecutor

orchestrator = Orchestrator(cell=cell)
orchestrator.executor = RoboChemExecutor(
    skills_executor,                                    # robochem SkillsExecutor
    param_overrides={"pour": {"forward_offset": -0.08}},  # bench-tuned values
    arm=cell.arm,                                       # for gripper bookkeeping
)
```

It is field-compatible with their `ExecutionResult` (`action`, `success`,
`reason`, `primitives_issued`, `simulated_seconds`, `is_fake`, `detail`,
`as_dict()`), so the whole logging path works unchanged — with `is_fake=False`,
which is the entire point. It provides:

- **Name translation.** The planner speaks the robot profile's *location*
  vocabulary (`"Original Position of clear cup 1"`); SAM 3 wants an object
  phrase (`"clear cup 1"`). `normalize_object_name()` strips the prefix.
- **Per-action parameter mapping**, covering all six actions. An unmapped or
  under-specified action fails explicitly rather than no-opping.
- **Real gripper-state guards.** Their `validate_sequence()` checks the plan;
  the bridge checks the *robot*. A plan that passes their checker can still
  arrive with an empty gripper because an earlier pick actually failed, and a
  `POUR` is then refused before the arm moves.
- **Pick-site memory.** `"PLACE at Original Position of beaker"` while holding
  the beaker cannot be segmented — the beaker is in the gripper, not there. The
  bridge records where each object was picked from and hands `place` those
  coordinates.
- **`build_position_lookup()`** — grounds the profile's workspace positions into
  base-frame coordinates. `hardware/real.py::RealFrankaArm.goto_delta` raises
  without one, noting *"the position lookup is populated by the perception stack
  at run start"*; this is that function, for anyone who does want the
  primitive-replay path instead.

The bridge imports nothing from `robomail_Aliyah` at load time — steps are
consumed structurally — so it stays importable and testable off the robot PC.
`scripts/test_skills_offline.py` cross-checks the mapping against their real
`action_vocabulary.py` when the package is present.
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

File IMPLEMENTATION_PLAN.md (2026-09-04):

# Autonomous Robotic Chemist - Implementation Plan

## Executive Summary

This project implements a **VLM-as-Orchestrator** system for wet-chemistry manipulation using a Franka Emika arm. The system reads instructions (from paper/screen), analyzes the scene, and executes chemistry tasks with closed-loop visual verification.

**Key Architecture**: Instruction Parser → Scene Analyzer → VLM Orchestrator → Skills Library → Visual Verification → Replan Loop

---

## System Architecture Overview

```
┌─────────────────────────────────────────────────────────────────────────────┐
│                         AUTONOMOUS ROBOTIC CHEMIST                          │
├─────────────────────────────────────────────────────────────────────────────┤
│                                                                             │
│  ┌──────────────────┐    ┌──────────────────┐    ┌──────────────────┐      │
│  │  INSTRUCTION     │───▶│  VLM ORCHESTRATOR │───▶│  SKILLS          │      │
│  │  PARSER          │    │  (GPT-4o/Claude)  │    │  EXECUTOR        │      │
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

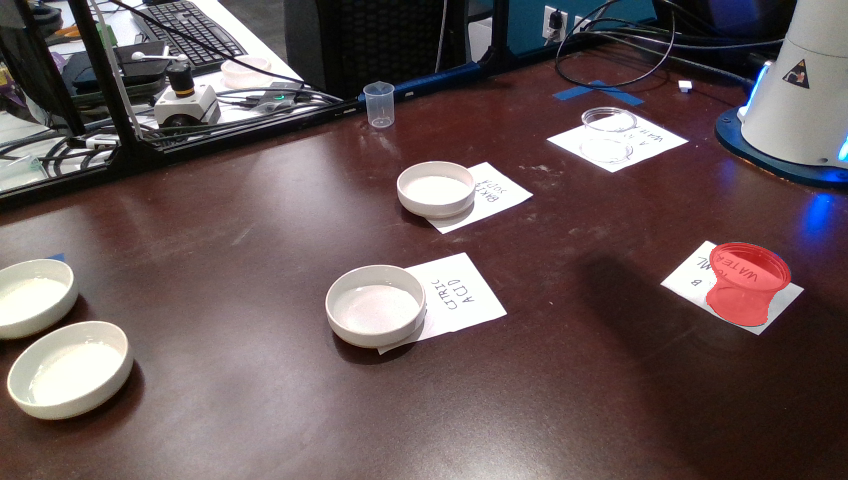
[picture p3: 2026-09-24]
diag_out/bowl_prompts/white_paper_cup_cam4.png

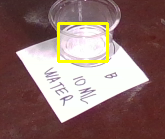
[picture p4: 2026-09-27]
diag_out/b10_cam2_crops/paper_cam2_inst3.png

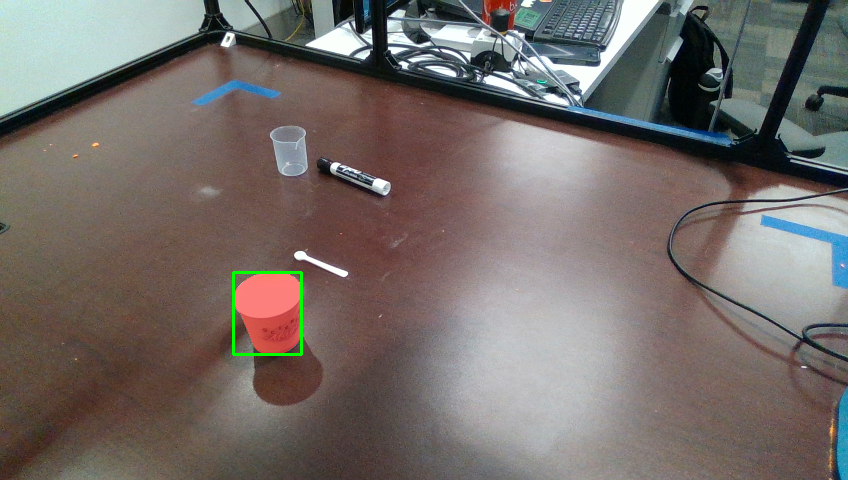
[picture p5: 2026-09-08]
diag_out/mask_white_paper_cup_cam5.png

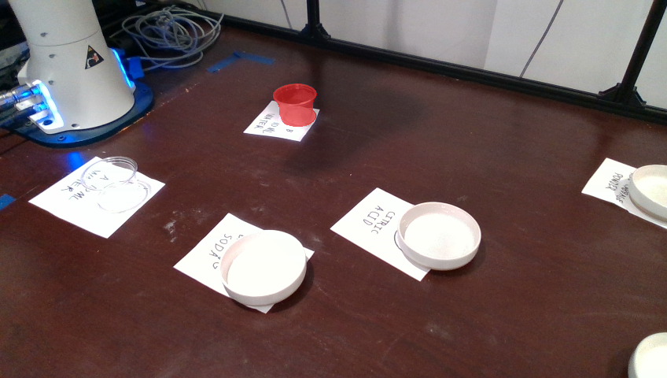
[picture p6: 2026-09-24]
diag_out/bowl_prompts/white_paper_cup_cam3.png

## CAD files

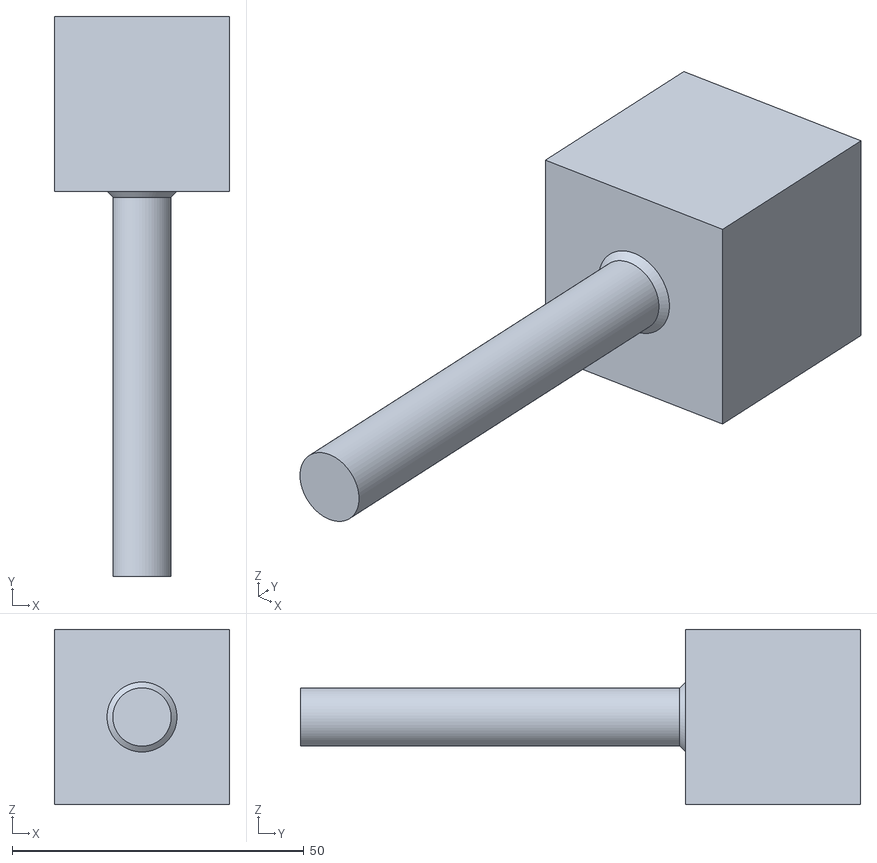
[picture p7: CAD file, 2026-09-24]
stirrer v1.stl
30.0 x 96.0 x 30.0

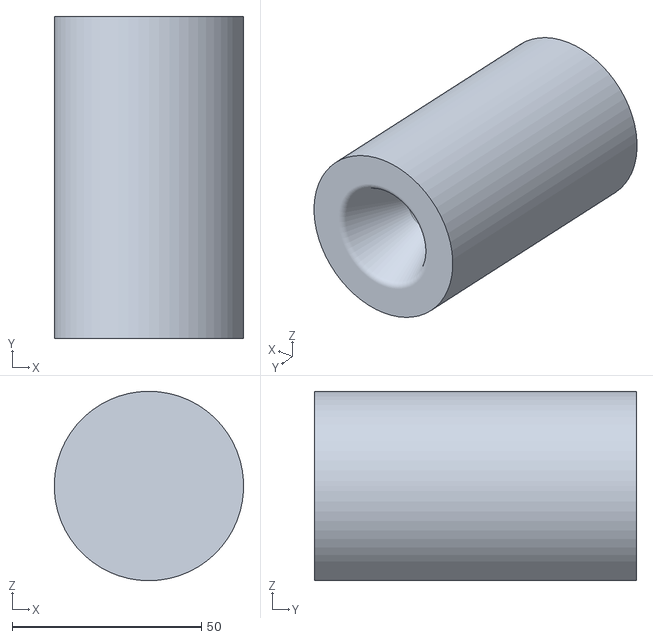
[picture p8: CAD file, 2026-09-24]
stirrer holder.stl
50.0 x 85.0 x 50.0

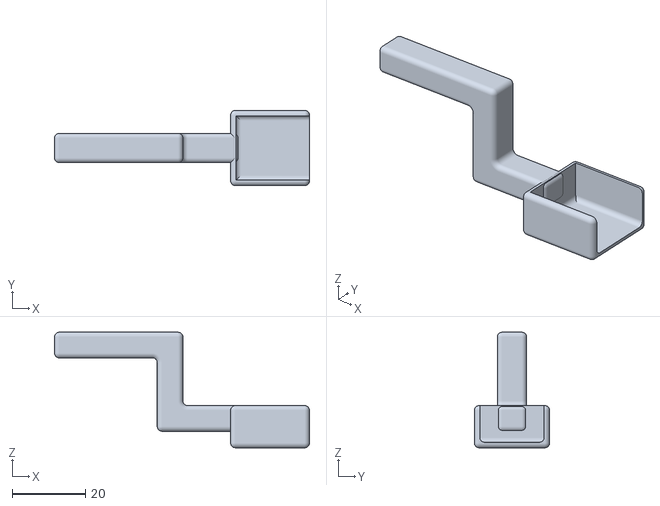
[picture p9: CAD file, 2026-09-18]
spoon.stl
69.5 x 20.5 x 31.5

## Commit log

2026-09-08 pour working, stage for next ready
2026-09-18 fix the scoop skill & add dump skill
    [spoon.stl]
2026-09-21 camera combination point cloud scan
2026-09-24 stirring finished in sim, and VLM orch started
    [stirrer holder.stl, stirrer v1.stl, stirrer_without_fins.STL]
2026-09-24 Fix stir regression from the bozhang merge; make env_dev.sh find the sim env
    The merge itself was clean, but combining both sides surfaced a real bug that
    neither branch hit alone: "pick + stir" passed on pre-merge main and failed
    after, with an 80mm gripper open stalling at 52.6mm and place.py reporting
    "Failed to open gripper".
    Cause: bozhang's _exclude_from_hand turns off hand/prop collisions while a
    prop is held, and the prop is teleported to follow the TCP. By release time
    its geoms overlapped the finger pads by 13.5mm (measured). _release restored
    the collision bits BEFORE the jaws moved, so MuJoCo resolved that overlap in
    one step and the recoil jammed the fingers.
    Fix: _release(def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
2026-09-24 Add a scoop-then-stir group that runs both with no reset between
    Every existing group starts with cell.reset(), which wipes the state one skill
    hands the next: what the jaws hold, where the arm was left, which geoms had
    their hand collisions switched off while a prop was carried. That is precisely
    where the merge's gripper bug lived, so no group could catch it.
    "scoop then stir" runs bozhang's pick_up + scoop + dump, puts the spoon down,
    then picks up the stirrer and runs stir + place -- one continuous session.
    Checked against the unfixed merge (4b90e52): it FAILS there at "stirrer placed
    back" with 'Failed to open gripper', and passes on the fixed tree. The spoon
    release alone does not cat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
2026-09-25 stir and pipeline added
    [stirrer_without_fins.STL]
2026-09-27 Model the powder dish exactly, fit the rim as a circle, fill in tool geometry
    Sim:
    - Powder dishes built to the bench measurements: 91 mm inside, 102 mm
    outside, 29 mm tall, 8 mm base. Prop gains floor_thickness and
    inner_radius / outer_radius / floor_height, which the scene, the powder
    estimate, film_sim_skill and the smoke test now read.
    - 18 mm of powder by default: with the tip 3 mm off the floor, shallower beds
    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
2026-10-04 Add VLM & whole pipeline
    Instruction (text or a photographed sheet) -> VLM plan -> execution in the
    MuJoCo sim, end to end, with the booklet's Magic Beaker as the test case.
    - Sim bench: the kit the Magic Beaker needs (three identical powder
    dishes, clear cups A/B/C at the measured 47.3 x 55.5 mm, the beaker with
    50 ml), laid out under rules measured from the arm's sweeps; random
    layouts swap like containers, then jitter.
    - robochem/sim/lab.py: powder carried by the scoops, liquid pour-over,
    dissolving, acid/base fizz and red cabbage colour, drawn for the cameras.
    - Skills: stir to_floor and a hand clearance; pour keeps the held cup's
    lip just over the target; scoop floor from the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
